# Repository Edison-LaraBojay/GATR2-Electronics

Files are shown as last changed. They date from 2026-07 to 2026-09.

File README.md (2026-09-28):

# GATR2 Electronics

Electronics, firmware, shared protocols, Raspberry Pi sensing software, and V5
Brain navigation libraries for the GATR2 VEX robot.

```text
encoders / IMU -> RP2040 acquisition -> Raspberry Pi estimation <-> V5 Brain
camera / other Pi-connected sensors ----------^
```

The Pi combines timestamped sensor measurements into robot localization and
information about a requested physical landmark. The Brain asks for them over a
request/reply link and owns destinations, alignment behavior, mechanisms, and
motor control.

## PCBs

The [PCB overview](pcb/README.md) links each board family. Its README explains
the general purpose, and the iteration folders document changes, test results,
and KiCad project files.

| Board family | Purpose |
|---|---|
| [Pi HAT](pcb/PiHat/README.md) | Plugs into the Pi's 40-pin header to reduce loose wiring and provide dedicated sensor and Brain connections. |
| [IMU](pcb/IMU/README.md) | Inertial measurements for attitude estimation, primarily heading. |
| [Magnetic encoder](pcb/MagneticEncoder/README.md) | Contactless rotation sensing for compact custom tracking-wheel assemblies. |

## Pi runtime

Start with [Set up and run Navigatr](pi/naviGATR/docs/setup.md) for Pi/Pico setup,
building, camera calibration, mounting measurements, two- and three-wheel IMU +
camera configurations, and the live field viewer.

The [Navigatr overview](pi/naviGATR/README.md) is the entry point for the Pi
runtime design, implementation coverage, and build commands. Its design uses
one program with independently scheduled localization and landmark-estimation
pipelines, standard stage inputs and outputs, and timestamped pose history.
Neither pipeline requires a particular sensor family or relative execution rate.

Robot position and field-object positions use configured field coordinates.
Field estimation starts with nominal landmark poses and can update them from
accepted observations. The Pi sends nothing unasked: each Brain request gets
one reply. A state reply carries the robot pose with its measurement age and
anchor identity; the field map (objects and their obstacle boxes) and the
current field-object estimates, labeled nominal or observed, are read as
chunked documents. Headings on the wire are full field headings, and the Brain
applies its own destination offset. The inspection viewer also displays
heading differences from nominal orientation. See the landmark documentation
for selection and retention behavior, and the
[brain link](docs/interfaces.md) for the wire contract.

- [Architecture and scheduling](pi/naviGATR/docs/architecture.md)
- [Coordinates and heading](pi/naviGATR/docs/coordinates.md)
- [Landmark reporting and retention](pi/naviGATR/docs/landmarks.md)
- [Inspection service and browser viewer](pi/naviGATR/docs/inspection.md)
- [Pi camera setup and libcamera build](pi/naviGATR/docs/pi_camera_setup.md)

A hardware-free demo (`pi/naviGATR/config/demo/`) drives the whole runtime
from a synthetic rig and serves the field viewer on loopback; the README above
has the run and SSH port-forward commands.

## Brain

[`brain/`](brain/README.md) holds portable C++ libraries with host tests and
the PROS programs that compile them in place.

- [investiGATR](docs/investigatr.md): path planning, direct and around the
  field's obstacle boxes, and the shared Brain types.
- [communiGATR](docs/communigatr.md): the Brain side of the Pi link over USB or
  RS-485: robot profile upload, field map, placement, calibration and recovery.
- [actuGATR](docs/actugatr.md): `goToDirect` and `goToAvoiding`, path
  following, tank and mecanum drives.

The Brain describes the robot (tracking wheels, IMU, footprint) and sends it
to the Pi as a robot profile; see [Brain setup](docs/brain_setup.md) for
configuration, calibration and the two test programs. The libraries are host
tested and compile in the PROS build; none of the Brain code has run on the
robot yet.

## Repository map

- [`pcb/`](pcb/) - KiCad boards, symbols, footprints, and hardware revisions.
- [`pico/aggreGATR/`](pico/aggreGATR/README.md) - RP2040 acquisition firmware.
- [`pi/naviGATR/`](pi/naviGATR/README.md) - Pi sensing and estimation runtime, with the spectaGATR browser viewer.
- [`brain/`](brain/README.md) - V5 Brain libraries (investiGATR, communiGATR, actuGATR) and PROS programs (locaGATR, operaGATR).
- [`translaGATR/`](translaGATR/) - shared wire codec used by the Brain, Pi and Pico.
- [`bench/`](bench/) - host and hardware bring-up utilities.
- [`docs/`](docs/) - supporting hardware, interface, and setup material; [component names](docs/naming.md).

## Hardware and bring-up references

- [Contributing](CONTRIBUTING.md)
- [Hardware architecture](docs/hardware.md)
- [Shared interfaces and wire frames](docs/interfaces.md)
- [Raspberry Pi setup](docs/pi_setup.md)

Physical values require measurement or independent verification. A `.xml.in`
configuration contains unresolved values and is not a deployment profile.

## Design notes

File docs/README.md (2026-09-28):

# Documentation

## Runtime and configuration

- [Set up and run Navigatr](../pi/naviGATR/docs/setup.md): complete Pi/Pico bring-up,
  camera calibration, robot geometry, three-wheel camera configurations, and the
  live viewer.
- [Parallel-wheel bring-up](../pi/naviGATR/docs/parallel_wheel_bringup.md): the
  current robot's systems test, two parallel wheels + BNO08X, localization
  first and camera second.
- [Navigatr](../pi/naviGATR/README.md): build, run, demo, and implementation coverage.
- [Configuration](../pi/naviGATR/docs/configuration.md): default profile, command-line
  overrides, inline XML, and referenced fragments.
- [Architecture](../pi/naviGATR/docs/architecture.md): construction, stage contracts,
  localization, field estimation, and workers.
- [Coordinates](../pi/naviGATR/docs/coordinates.md): frames, heading, camera offsets,
  measurement time, and pose history.
- [Landmarks and targets](../pi/naviGATR/docs/landmarks.md): association, retained
  field estimates, target resolution, and the actual Brain output.
- [Resources](navigatr_resources.md) and [sensors](navigatr_sensors.md): registered
  implementations and their configuration contracts.
- [Inspection](../pi/naviGATR/docs/inspection.md): the spectaGATR browser
  viewer, the `navigatr.inspect/2` feed (state, diag, telemetry,
  instrumentation), latency terms, live graphs and replay.
- [Capture and export](../pi/naviGATR/docs/capture.md): bounded Pi-side
  recording with manual and automatic triggers, the ZIP of CSVs and its
  metadata.
- [Camera preview](../pi/naviGATR/docs/camera_preview.md): live camera
  pictures on the Brain-profile USB setup without field correction.
- [Pico link](../pi/naviGATR/docs/pico_link.md): Pico identity, status,
  commands, the optional diagnostic frame and the link instrumentation.
- [Viewer perf harness](../pi/naviGATR/tools/perf/README.md): the inspection
  and browser latency baseline and how to rerun it.

## Brain

- [Brain setup](brain_setup.md): where robot settings live, building and
  uploading, the localization test and drive test programs, wheel and IMU
  calibration, placement, recovery, and what is not yet hardware validated.
- [investiGATR](investigatr.md): path planning and the shared Brain types
  (field, state source, references, motion model, paths); planner method,
  exits by walls, cost and limits.
- [communiGATR](communigatr.md): the Pi link over USB or RS-485: sessions,
  robot profile, field transfer, placement, calibration, recovery, timing,
  PROS packaging.
- [actuGATR](actugatr.md): movement commands, path following, tank and
  mecanum drives, drive ownership, tuning.
- [Brain folder](../brain/README.md): libraries, PROS programs, and the host
  build.

## Hardware and deployment

- [PCB overview](../pcb/README.md): board families, revisions, and validation status.
- [Hardware](hardware.md): sensor roles, firmware settings, and communication wiring.
- [Pico firmware](../pico/README.md): acquisition and sensor telemetry.
- [Wire interfaces](interfaces.md): Pico sensor frames and control, and the brain
  link v4 request/reply protocol (sessions, profile, documents, bus timing).
- [Pi access](pi_setup.md): SSH and provisioning.
- [Pi camera setup](../pi/naviGATR/docs/pi_camera_setup.md): libcamera build and
  capture checks.
- [Field assets](../pi/naviGATR/docs/field_assets.md): nominal Override geometry and
  its CAD sources.
- [Calibration inventory](../pi/naviGATR/docs/calibration_inventory.md): required
  robot measurements and template values.
- [Attitude firmware follow-up](../pi/naviGATR/docs/attitude_firmware_followup.md):
  the work needed to provide live roll and pitch.
- [RS-485 bench test](../bench/rs485_link/README.md): independent transmit bring-up.

[Component names](naming.md) lists every -GATR name, what it does and why
it fits, and the renames with migration steps.

[Contribution conventions](contributing/README.md) describe the repository layout
and how to add board families and revisions. Host tests and synthetic demos verify
software behavior; hardware validation status is recorded in the relevant board
and deployment documents.

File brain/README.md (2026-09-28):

# brain

V5 Brain software. The libraries are portable C++ with host tests; PROS
programs compile them in place from this folder.

- [`investiGATR/`](investiGATR/README.md): path planning (direct and obstacle
  avoiding) and the shared Brain types: field, state source, references,
  motion model, paths.
- [`communiGATR/`](communiGATR/README.md): the Pi link over USB or RS-485:
  sessions, robot profile upload, field map and estimates, placement,
  calibration and recovery, wheel calibration, telemetry and VEX IMU tilt
  for the Pi viewer.
- [`actuGATR/`](actuGATR/README.md): movement: `goToDirect` and
  `goToAvoiding`, path following, tank and mecanum drives, the drive task.
- [`robot/`](robot/README.md): this robot's description (tracking wheels,
  IMU, footprint, link, start pose), shared by the programs.
- [`locaGATR/`](locaGATR/README.md): motor-free bench
  program: placement, pose, IMU and wheel calibration, recovery history.
- [`operaGATR/`](operaGATR/README.md): drive program: direct, avoiding and
  landmark tests, manual driving, tuning.
- `gatr2_brain.mk`: make fragment that compiles the libraries into a PROS
  project.
- `CMakeLists.txt`: host build and tests of the three libraries.

Host build and tests, from the repository root (the CI job `brain` runs the
same commands; CI does not build the PROS programs):

```
cmake -S brain -B build-brain
cmake --build build-brain -j
ctest --test-dir build-brain --output-on-failure
```

Setup, calibration, tuning and the test programs:
[Brain setup](../docs/brain_setup.md). Libraries:
[investiGATR](../docs/investigatr.md), [communiGATR](../docs/communigatr.md),
[actuGATR](../docs/actugatr.md), [wire interface](../docs/interfaces.md).
Nothing here has run on the robot yet.

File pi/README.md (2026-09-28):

# Raspberry Pi sensing runtime

[`naviGATR`](naviGATR/README.md) combines timestamped measurements into a robot
pose and configured field-object estimates. Target resolution can latch a desired
robot pose for a requested target; the V5 Brain owns motor control.

The runtime uses independently scheduled estimation and field
pipelines in one program. Each pipeline has defined inputs and outputs; its
implementation determines which sensors and algorithms it uses.

Start with [Set up and run Navigatr](naviGATR/docs/setup.md) for the complete
hardware, calibration, configuration, build, and viewer workflow. The
[runtime overview](naviGATR/README.md) describes implementation coverage; then read:

- [Architecture and scheduling](naviGATR/docs/architecture.md)
- [Coordinates, heading, and measurement time](naviGATR/docs/coordinates.md)
- [Field estimates, targets, and reporting](naviGATR/docs/landmarks.md)

The overview includes implementation coverage and build commands.

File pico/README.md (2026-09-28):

# pico

RP2040 software for the Pi HAT.

- [`aggreGATR/`](aggreGATR/README.md): the acquisition firmware (PlatformIO project). It gathers the encoder counts and IMU readings into timed frames for the Pi. Build it from `pico/aggreGATR` with `pio run`.

Component names: [docs/naming.md](../docs/naming.md).

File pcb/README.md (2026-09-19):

# PCBs

Custom boards for the GATR2 sensing system. Each board folder explains its
general purpose and contains its numbered iterations. Each iteration has its
own README describing changes, status, and KiCad project files.

## Boards

| Board | Purpose |
|---|---|
| [Pi HAT](PiHat/README.md) | A stable connection through the Pi's 40-pin header, with dedicated sensor and peripheral ports to reduce loose wiring. |
| [IMU](IMU/README.md) | Inertial measurements for robot attitude estimation, primarily heading. |
| [Magnetic encoder](MagneticEncoder/README.md) | Contactless rotation sensing for compact custom tracking-wheel assemblies. |

## Working with a board

Choose a board, then an iteration, and open the `.kicad_pro` linked from its
README. Keep the schematic, layout, and accompanying libraries together.

The Pi HAT symbol tables and the magnetic encoder's symbol table still contain
workstation-specific library paths. The Pi HAT's custom symbols are included in
its `RP4Pinout/` directory; library paths may need updating when editing on
another machine. Project locations and library notes are linked from each
revision README.

When a revision changes, update its short description and the comparison with
the previous revision. Record fabrication or test results alongside that
revision when available. The schematic remains the source for the BOM and
connector pin assignments.

For new boards and iterations, follow the
[PCB contribution guide](../docs/contributing/README.md).

## Related documentation

- [Hardware parts and rationale](../docs/hardware.md)
- [RP2040 acquisition firmware](../pico/README.md)
- [Pi sensing and estimation software](../pi/navigatr/README.md)
- [Shared interfaces](../docs/interfaces.md)

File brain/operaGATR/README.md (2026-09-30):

# brain/operaGATR

PROS drive program for the V5 Brain: localization from the Pi through
communiGATR, planning from investiGATR, following and drive control from
actuGATR. It runs a direct, an avoiding and a landmark-relative test, drives
manually, and shows the command state for tuning. Built with the PROS
toolchain; manual driving has been tested, and autonomous following still
needs hardware verification.

The current test uses USB to the Pi, a VEX IMU on Smart Port 20, a forward
tracking wheel on Pico port 1 and a sideways wheel on port 0. Four-motor
mecanum is selected, with one independently driven motor per corner, confirmed
blue 600 RPM cartridges and 1:1 direct drive (motor, shaft, wheel). Tracking
wheels remain approximately 48 mm in diameter with 4,000 counts per turn.
Temporary distance multipliers in `brain/robot/gatr2_robot.h` are **2.10144**
for the forward wheel (port 1) and **1.96700** for the sideways wheel (port 0),
from separate 23-inch pushes that reported 0.278 m and 0.297 m respectively.
These multiply the radius sent in the robot profile because the existing Pi
limits `travel_scale` to 0.9–1.1; the transmitted radii are effective calibration
values, not physical wheel sizes. Rebuild/upload the Brain and restart its
program to send the profile; no Pi update is needed. Repeat the distance test
before path testing. Reset these multipliers to 1.0 before correcting the
underlying CPR, gearing or wheel diameter. Port 2 retains its nominal radius.
The driven-wheel rectangle is 22.3 cm wide between tread centerlines and
24.2 cm long between front/rear shafts; its center is the robot origin.

The mecanum wheels are approximately 70 mm in diameter. Motor Smart Ports are
front-left 12, front-right 11, rear-left 2 and rear-right 1, named while facing
forward from behind the robot.
The reversal flags in `include/robot_config.h` set ports 2/12 normal and
ports 1/11 reversed so positive wheel commands should roll forward. Verify
forward/backward, strafe and turning with this configuration before path tests.
The tracking-wheel perpendicular offsets in `brain/robot/gatr2_robot.h` use these approximate
measurements: the forward wheel is at the right tread centerline, giving
y = -11.15 cm; the sideways wheel is assumed 11 cm behind the front axle,
giving x = +1.1 cm. Robot +x is forward and +y is left.
Both tracking encoders use `reversed = true`. At field heading 0 degrees,
a forward push should increase X and a leftward push should increase Y;
confirm those signs after uploading before running a path.
The outer body measures approximately 33.7 by 29.3 cm. Its footprint uses
16.85 cm forward/backward and 14.65 cm left/right from the drivetrain origin:
front/back overhangs are roughly equal, and left/right symmetry is assumed.
Refine individual extents if needed before close obstacle passes.
The geometry is approximate; motor/encoder directions and gains still need
checking and tuning on the robot.

Mount the mirrored wheels so the roller directions form an X when viewed from
above. Matching wheel types occupy opposite diagonals. The motor groups are
front-left, front-right, rear-left and rear-right; motor reversal makes each
wheel roll forward for a positive command, and cannot correct a misplaced
wheel type. The software does not have a per-wheel A/B handedness option.

Keep the robot still at startup. Once the profile, sensors and placement are
ready, its initial pose is (7 inches, 24 inches, 0 degrees). Left stick Y drives forward/back,
left stick X strafes, and right stick X turns (robot-relative controls).
Press A with the sticks released to plan from the
current pose to the fixed target (72 inches, 24 inches, 90 degrees), without
obstacle checks. X uses that same target with obstacle avoidance.
Moving manually first changes the path's start, not its target.
On the configured field, the direct route crosses `red_goal_3_south` near
(46.66 inches, 23.11 inches), so use X with the field assembled. The initial
rear clearance to the red wall is only about 9 mm with the approximate
footprint. Avoidance supports a straight exit from this near-wall placement.
The holonomic follower can translate and change heading at the same time.
B cancels; moving the sticks also takes over. UP reassigns the current pose to
the initial pose, so only use it after returning to the physical starting spot.
Encoder directions and follower gains still need checking on the robot.
To request a fresh VEX IMU calibration, press DOWN while stopped, keep the
robot still until it finishes, then press UP at the physical starting spot.

The Pi still serves the pose and path visualization; no camera is required.
Use `pi/naviGATR/config/override/brain_profile_usb.xml`. The Brain sends these
robot measurements to the Pi, so changing them only requires rebuilding and
uploading this Brain program. A ignores obstacles and field bounds; X/Y
check them using the configured footprint and planning clearance.

Edit the initial pose in `brain/robot/gatr2_robot.h`: `kStartX`, `kStartY`
(inches multiplied by `kInch`) and `kStartHeadingDegrees` (degrees).
Edit `kDirectGoal` in `include/robot_config.h` for the A/X destination:
`{x_inches * kInch, y_inches * kInch, heading_degrees * kDeg}`.
`kAvoidGoal` takes the same value automatically. Keep the robot's physical
center at the configured start and facing the configured heading at startup,
or when using UP to reassign its pose.

- `include/robot_config.h`: drivetrain (tank or mecanum example), motor
  ports and directions, limits, follower gains, manual speeds, test
  destinations, startup placement. PLACEHOLDER values are not measured.
- `include/field_references.h`: generated field object names
  (`Field::RedGoal2West`, ...) for the map id the Pi serves.
- `src/main.cpp`: link and drive setup, the screen, `autonomous()`,
  `opcontrol()`, `disabled()`. The actuGATR drive task is the only motor
  writer.
- The robot description (tracking wheels, IMU, footprint, link, start pose)
  is shared with locaGATR in
  [brain/robot/gatr2_robot.h](../robot/gatr2_robot.h).
- `Makefile`: PROS kernel 4.2.2 project that compiles the libraries in place
  through [brain/gatr2_brain.mk](../gatr2_brain.mk).

Kernel files (`firmware/`, `include/pros/`) are not in git. Restore them once,
offline, in this folder:

```
pros c apply kernel@4.2.2 --force-apply --no-download
git checkout -- .gitignore
pros make
pros upload --slot 1 --name operaGATR --after screen
```

The CLI replaces `.gitignore` with its template copy, hence the checkout.

Controls, tests, tuning and the planner limits:
[Brain setup, section 7](../../docs/brain_setup.md#7-drive-test-program).

While the link is disconnected, the screen replaces the button hints with
connection diagnostics from the existing status snapshot. `I/O on` means
the Brain transport is initialized, not that the Pi has answered. USB `tx`
counts complete line writes, `rx` decoded incoming frames, and `short`
incomplete writes. `Reply` counts correlated protocol replies, `TO` timeouts,
`bad` invalid reply frames, and `stray` valid replies without a matching
request. The last diagnostic row shows USB read errors/dropped lines and
whether the polling task started, or an explicit protocol mismatch.
Photograph these rows if the program remains at connecting; the counters
distinguish a transmit stall, missing responses, and rejected responses.

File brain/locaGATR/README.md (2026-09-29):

# Localization test

Motor-free PROS bench program for checking naviGATR localization. It sends
the robot profile from [brain/robot/gatr2_robot.h](../robot/gatr2_robot.h)
to the Pi, places the robot once at program start, and shows pose,
readiness, sensors and recovery history on the Brain screen. It also runs
the per-wheel travel calibration and IMU recalibration. Move the robot by
hand. Built with the PROS toolchain; not yet run on a robot.

Current bench setup (all in `gatr2_robot.h`):
- USB link to the Pi;
- two perpendicular tracking wheels, forward on encoder port 1 and sideways
  on port 0;
- the VEX IMU on Smart Port 20.

The Pi runs `config/override/brain_profile_usb.xml`. No BNO08X, camera or
AprilTags are needed.

- `include/robot_config.h`: startup placement policy and wait, wheel
  calibration reference distance and limits, pose age limit, loop periods.
- `src/main.cpp`: three pages (Status, Wheel calibration, Recovery). Every
  link call is in its first section.
- `Makefile`: PROS kernel 4.2.2 project that compiles the libraries in place
  through [brain/gatr2_brain.mk](../gatr2_brain.mk).

Kernel files (`firmware/`, `include/pros/`) are not in git. Restore them once,
offline, in this folder:

```
pros c apply kernel@4.2.2 --force-apply --no-download
git checkout -- .gitignore
pros make
pros upload --slot 2 --name locaGATR --after screen
```

The CLI replaces `.gitignore` with its template copy, hence the checkout.

Pages, controls, the calibration procedure and recovery:
[Brain setup, sections 3 to 6 and 8](../../docs/brain_setup.md#3-locaGATR-program).
Pi build and service: [Brain setup, section 2](../../docs/brain_setup.md#2-build-and-upload).

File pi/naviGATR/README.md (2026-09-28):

# navigatr

`navigatr` is the Raspberry Pi sensing runtime for the GATR2 VEX robot. It
combines measurements into a robot pose and field-object estimates. Configured
target resolution can turn a requested target into a desired robot pose; the
Brain owns movement control and motor commands.

Robot position and reported landmark position use the configured field
coordinates. Robot heading is its orientation in that field. The landmark's
inspection `heading_error` is its estimated rotation away from nominal, wrapped
to `(-180, 180]` degrees. The brain link answers Brain requests only. Its field
documents carry every configured object: the map with collision boxes, and the
estimates as physical poses with full field heading, labeled nominal or
observed. Configured targets stay on the Pi.

**Robot configuration comes from the Brain.** The primary configs,
[`config/override/brain_profile_usb.xml`](config/override/brain_profile_usb.xml)
and [`brain_profile_rs485.xml`](config/override/brain_profile_rs485.xml), hold
only the Pi's devices, wired ports and tuning; the Brain sends the tracking
wheels, encoders, IMU source and footprint as a typed robot profile, and the
Pi builds its localization from it. See [Brain robot profiles](docs/brain_profile.md).

## Runtime design

**First setup:** [Set up and run Navigatr](docs/setup.md) starts with the
Brain-profiled robot, then covers Pi/Pico provisioning, build commands, camera
calibration software, robot and camera geometry, the XML-configured
three-wheel IMU + camera templates, launch commands, and output locations. The
two parallel wheels + BNO08X XML profiles have their own
[bring-up guide](docs/parallel_wheel_bringup.md). The current bench (USB, VEX
IMU, forward and sideways wheels) is in [USB bench](docs/usb_localization_bench.md);
[Pi setup and automatic startup](../../docs/pi_setup.md) covers Ethernet
access, building, and starting naviGATR on every boot.

These documents describe the implemented runtime and data contracts. Hardware
integration still needs the checks recorded in the deployment documents.

| Document | Responsibility |
|---|---|
| [Brain robot profiles](docs/brain_profile.md) | The Brain-profiled configs: who owns what, apply and continuity, supported setups and refusals, corrections applied once, calibration and stationary handling, CONTROL, sensor loss and recovery. |
| [USB bench](docs/usb_localization_bench.md), [VEX IMU bench](docs/vex_imu_bench.md) | The current bench: USB link, forward and sideways wheels, the Brain VEX IMU. |
| [Pico link](docs/pico_link.md) | Pico identity, status, commands and the serial reopen. |
| [Configuration](docs/configuration.md) | Run commands, the compiled default file, inline XML, and nested file references. |
| [Architecture](docs/architecture.md) | Captured resource/sensor functions, ResourceMap and SensorMap result contracts, all runtime paths, nested stage I/O, workers, and pose history. |
| [Coordinates](docs/coordinates.md) | Field and robot axes, heading, camera mounting, attitude, and measurement-time transforms. |
| [Landmarks](docs/landmarks.md) | Nominal and observed field state, association, target resolution, and Brain output. |
| [Inspection](docs/inspection.md) | The `navigatr.inspect/2` feed, flow control and latency terms, the service, and the spectaGATR browser viewer. |
| [Capture](docs/capture.md) | Bounded Pi-side diagnostic recording, triggers, the ZIP/CSV bundle and its metadata. |
| [Camera preview](docs/camera_preview.md) | The camera shown on the Brain-profile USB setup with no field correction. |
| [Perf harness](tools/perf/README.md) | Inspection and viewer latency measurements: baseline, rerun, compare. |
| [Localization fusion](docs/localization_fusion.md) | Noise units, the weighted step, covariance propagation, and what the fusion estimator does not model. |
| [Field assets](docs/field_assets.md) | Official Override CAD source, revision, units, axis conversion, planning data (boundary, wire ids, collision boxes), and what the field file was checked against. |
| [Calibration inventory](docs/calibration_inventory.md) | Every remaining measurement, where it goes, and what it gates. |
| [Pi camera setup](docs/pi_camera_setup.md) | libcamera stack, build flag, capture mode, exposure timing convention, hardware checks still to run. |
| [Attitude follow-up](docs/attitude_firmware_followup.md) | What the Pico firmware would have to send for live tilt. |

## What runs

One executable, built once from a configuration, with two workers and an
optional inspection service:

```text
construction   parse -> make_resources -> make_sensors -> make_localization
               -> make_world_estimation -> target resolution, publishing slots
               -> freeze (any failure destroys the candidate)

estimation     resources -> sensors -> commands -> localization
worker         -> target resolution + publishing against the newest field snapshot
(loop rate)    -> hands the sensor snapshot to the field worker (latest wins)

field worker   world estimation (apriltag: extraction -> association -> landmarks)
(event driven) -> publishes an immutable FieldSnapshot and the detection frame
               bound to its exact image identity

inspection     reads snapshots only; JSON + JPEG over loopback HTTP/WebSocket
service        at its own rate; a slow browser is skipped, never waited for
```

Localization is a self-contained component: configured robot-observation
functions grouped by measurement model (`tracking_wheel_motion`,
`imu_heading_increment`, `attitude_reference`, and the Brain VEX IMU bench
models `brain_imu_planar_bench` and `brain_imu_parallel_bench`), one state estimator
(`planar_motion_integrator`, or `weighted_planar_fusion` with an explicit
uncertainty model and a pose covariance), and a history ring of recent poses that only
localization writes. Readers get copied snapshots or synchronized timestamped
lookups (`RobotStateFeed`). Every mutable state has one writer; `reset()` stops
both workers, resets every stage once, and restarts them.

## Implementation coverage

Implemented and covered by host tests:

- Aggregate stages `make_resources`, `make_sensors`, `make_localization`,
  `make_world_estimation` with captured executors; typed result maps with receipt, provenance, sequence and
  epoch preserved through derived records.
- Tracking-wheel odometry with gyro heading, per-source interval alignment,
  encoder rebase on a source restart, rejection of nonpositive intervals, no
  endpoint bridging of invalid spans; optional attitude (quaternion) reconciled
  with the planar heading, aged separately, level fallback labeled assumed.
- Covariance-weighted fusion (`weighted_planar_fusion`): three wheels plus an
  independent gyro blended by configured noise, translation re-solved through
  the wheel geometry, pose covariance propagated; the checked-in
  `config/demo/synthetic_fusion_demo.xml` runs it against the rig.
- Pose history ring (binary search, shortest-arc yaw interpolation, attitude
  slerp, gap and epoch gates, explicit lookup statuses).
- Real AprilTag detection (vendored AprilRobotics detector, `tagCircle21h7` and
  the other supported families) with 2D decoding without calibration, metric
  poses only with intrinsics and a configured corner size, distortion undone
  before the solve, every decoded tag visible with its association decision.
- Capture-time transform chain with the camera offset, mounting rotation and
  measured tilt; association by full pose against every mount sharing an id.
- Two-worker scheduling with a bounded latest-frame handoff, per-worker rate
  and drop counters, orderly shutdown.
- Inspection feed `navigatr.inspect/2` (latest-state delivery with ping/pong
  flow control, separate state and diag messages; the full `inspect/1`
  snapshot stays at `GET /api/snapshot`), the service, and the spectaGATR
  three.js viewer (field, robot and attitude, trail, nominal vs estimated
  landmarks, camera image with identity-bound overlays, status badges,
  diagnostics, latency panel, live graphs, transport instrumentation,
  capture controls and ZIP replay).
- Diagnostics: a bounded `DiagnosticsHub` fed by the runtime's producers,
  always-on link counters, and a Pi-side capture service with triggers that
  writes a store-only ZIP of CSVs.
- A synthetic rig resource that drives the real pipeline without hardware:
  encoder counts, gyro with bias, attitude (measured or unavailable), rendered
  camera frames of the configured field, a displaced landmark.

Implemented but not run on hardware (see the Pi camera setup document for the
exact checks): the libcamera capture backend (`libcamera_camera`, built only
with `-DNAVIGATR_WITH_LIBCAMERA=ON` on the Pi) including exposure timestamp
mapping and buffer ownership.

Implemented and host tested, not run on hardware:

- The brain link (`brain_link` command collection and publishing, Brain link
  v4 sessions, per-session dedupe, placement acknowledged only once applied)
  over the half-duplex `linux_serial_link` (`DriverEnable`) or the Brain USB
  port (`pros_usb_link`). The hardware checks are in
  [Connect the Brain](docs/setup.md#hardware-checks-still-to-do).
- Brain robot profiles: staging, validation, capability checks, the candidate
  built from Pi templates, the controlled boundary and its continuity rules,
  every supported topology and IMU source, each correction applied once.
- Field documents for Brain planning (map with collision boxes, estimates of
  every object), chunked and retained.
- One stationary window for every IMU bias path, bounded calibration with
  gated bias upkeep, zero velocity while stationary; CONTROL recalibrate,
  reinitialize, Pico IMU reinit and acquisition restart; READ_WHEELS.
- Recovery: a used source that drops ends pose continuity (the Brain places
  again); Pico identity and restarts; serial reopen; a bounded event log.
- Inspection of all of it: the Brain link state, profile, wheels, calibration,
  Pico link, events and path, and the field's planning data in the viewer.

Deferred, deliberately:

- Live tilt from the Pico: the firmware sends gyro Z alongside encoders; the
  protocol has optional accel XY fields, but the firmware does not populate
  them, so Pico IMU profiles show attitude `assumed_level`. Brain VEX IMU
  profiles get roll and pitch from Brain TELEMETRY for display and recording
  (`measured`, then `stale` 250 ms after the last report); VEX sign
  conventions are not yet checked on hardware. The estimator attitude path is
  exercised by the synthetic rig.
- Manual exposure and gain control for the camera (auto exposure is used).
- Measured calibration values for the GATR2 robot: the robot templates stay
  `.xml.in` until measured (see the calibration inventory).

Synthetic tests and desktop browser checks do not establish Pi camera
performance or physical alignment accuracy.

## Configuration and calibration

XML selects registered implementations and supplies their configuration. IDs are
opaque references. Startup checks reject missing producers, incompatible payloads,
duplicate outputs, and invalid calibration.

- [`config/shared/robots/`](config/shared/robots/): the GATR2 robot templates
  (`.xml.in`, measured values required), the uncalibrated camera fragment for
  live inspection, and the synthetic rig fragments.
- [`config/shared/pipelines/`](config/shared/pipelines/): the parallel-wheel
  pipelines and their shared localization, three-wheel diagnostic pipelines, the
  synthetic demo pipeline, and the camera-only inspection pipeline.
- [`config/override/brain_profile_usb.xml`](config/override/brain_profile_usb.xml),
  [`brain_profile_rs485.xml`](config/override/brain_profile_rs485.xml): the
  primary robot configs; the Brain supplies the robot profile.
- [`config/override/field.xml`](config/override/field.xml): nominal Override
  geometry for nine goals and their tag mounts, the planning data (boundary,
  wire ids, collision boxes), plus display dimensions and static features.
- [`config/override/diagnostics/`](config/override/diagnostics/): the
  XML-configured profiles: the VEX IMU bench profiles, the parallel-wheel
  profiles (runnable once their robot file is measured), composed three-wheel
  profile templates, and the runnable live camera inspection profile.
- [`config/demo/`](config/demo/): hardware-free demo profiles.
- [`config/examples/modular/main.xml`](config/examples/modular/main.xml): a minimal
  runnable scaffold with separate Resources, Sensors, Pipeline, and Localization files.

Files ending in `.xml.in` contain unmeasured or unresolved values and cannot be
loaded. `calibration_status` is an optional reader annotation that runtime
does not interpret; actual parameter values and geometry are validated.
Display metadata (`Dimensions`, `Feature`,
`Visual`) never feeds an estimate.

## Build

Host (Windows, Git Bash, from `pi/naviGATR`):

```text
export PATH=/c/msys64/ucrt64/bin:$PATH
cmake -S . -B build -G "MinGW Makefiles" -DCMAKE_BUILD_TYPE=Debug
cmake --build build -j8
ctest --test-dir build --output-on-failure
```

Pi (Raspberry Pi OS, from `pi/naviGATR`; packages in the Pi camera setup
document):

```text
cmake -S . -B build -DCMAKE_BUILD_TYPE=Release -DNAVIGATR_WITH_LIBCAMERA=ON
cmake --build build -j4
ctest --test-dir build --output-on-failure
```

Without `NAVIGATR_WITH_LIBCAMERA`, selecting `libcamera_camera` is a
configuration error naming the missing backend; nothing pretends to capture.

## Run

```text
./build/navigatr [--config_file="profile.xml"] [--inspect-port <n>]
                 [--cycles <n>] [--inline] [--replay <resource_id>=<capture.bin>]
```

- With no filename, the initial compiled default is
  `config/demo/synthetic_field_demo.xml`. Select another at build time with
  `cmake -S . -B build "-DNAVIGATR_DEFAULT_CONFIG=config/my_robot.xml"`, then rebuild.
  The chosen path is baked in; XML contents are read on each startup.
- `--config_file` overrides that choice for one run; `--config-file` and the
  positional filename also work. `--help` prints the compiled default path.
- Default execution: workers plus the inspection service when the profile enables it.
  Ctrl-C stops the service, then the workers, then the system.
- `--inline` runs every stage on one thread at the loop rate (replay, bench).
  The brain link needs the default workers; `--inline` with it prints a warning.
- `--inspect-port` enables the inspection service on loopback without editing
  the profile.

Hardware-free demo with the viewer:

```text
./build/navigatr
./build/navigatr --config_file="config/demo/synthetic_field_demo_no_attitude.xml"
./build/navigatr --config_file="config/demo/synthetic_fusion_demo.xml"
```

The robot, configured from the Brain (Pi; RS-485: `brain_profile_rs485.xml`):

```text
./build/navigatr --config_file="config/override/brain_profile_usb.xml"
```

It waits for the Brain's profile; `event: ...` lines log applies, refusals,
sensor loss and recovery.

Live camera inspection before metric calibration (Pi, libcamera build):

```text
./build/navigatr --config_file="config/override/diagnostics/live_camera_inspection.xml"
```

From the viewing computer, forward the port and open the page:

```text
ssh -N -L 8765:127.0.0.1:8765 <user>@<pi-host>
http://127.0.0.1:8765/
```

The browser smoke test (`tools/viewer_smoke.sh`) starts the demo, loads the
page headless, and checks that states and a detection frame arrived. The
full browser suite is `py -3 tools/viewer/viewer_tests.py all --binary
build/navigatr.exe` (headless Chrome or Edge; unit, live, no-WebGL,
reconnect, replay, record, slow client, capture failure).

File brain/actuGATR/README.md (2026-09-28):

# actuGATR

Brain-side movement: `Motion` (`goToDirect`, `goToAvoiding`), path followers,
tank and mecanum drive kinematics, the drive owner, PROS motor adapters, and
the TELEMETRY movement and wheel groups (`telemetryOf`).
Plans come from investiGATR; robot state and the field come from any
`investigatr::StateSource` (communiGATR over the Pi link).

- `include/actugatr/`: public headers
- `src/`: portable sources, host and PROS
- `pros/`: PROS-only sources (motor output, drive task)
- `sim/`: host drivetrain sim, simulated state source, test planner
- `tests/`: host tests; `trajectory_gtest.cpp` runs with the real planner

Usage, tuning and limits: [docs/actugatr.md](../../docs/actugatr.md).

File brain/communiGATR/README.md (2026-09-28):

# communiGATR

Brain side of the Pi link (brain link v4) over USB or RS-485. It sends the
robot profile, reads the field map and estimates, places the robot, runs
calibration and recovery actions, and gives planning and control the robot
state as an investiGATR `StateSource`. It does not plan or drive.

- `Client`: the protocol over a `BytePort`, polled with a time; no I/O of its
  own, no threads.
- `LinkDriver`: `StateSource` and `PathSink` over the client, in SI units.
- `RobotProfile`: the robot description, checked with the Pi's rules before
  upload.
- `readiness`: the status summary both programs show.
- `ProsLink` (PROS): one class for both transports, with its own poll task
  and bounded locks. `ProsVexImu` (PROS): the Brain VEX IMU bench source.
- `attitude`: VEX IMU roll and pitch in the robot frame, for TELEMETRY.
- `VexImuRecalibration`: starts the VEX IMU calibration only after the Pi
  reports the robot still.
- `wheel_calibration`, `startup_placement`, `link_events`: application
  helpers.

Folders:

- `include/communigatr/`: public headers (`pros_*.h` are PROS only)
- `src/`: portable sources, host and PROS
- `pros/`: PROS only sources, never built on the host
- `sim/`: host only fake Pi, RS-485 bus, USB console and test rig
- `tests/`: host tests

Docs:

- [communiGATR](../../docs/communigatr.md): API, profile, field sync,
  readiness, recovery, timing, PROS packaging, tests.
- [Wire interface](../../docs/interfaces.md): brain link v4 and documents.
- [Brain setup](../../docs/brain_setup.md): where settings live, build and
  upload, calibration, placement.
- [actuGATR](../../docs/actugatr.md): movement on top of this link.

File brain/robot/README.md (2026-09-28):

# robot

`gatr2_robot.h`: this robot's localization description, shared by the Brain
programs (tracking wheels, encoders, IMU source, footprint, Pi link, start
pose), plus the telemetry switch and the VEX IMU mounting for the viewer's
tilt. The Brain sends the localization part to the Pi as the robot profile on
connect.
Program-specific settings (drive motors, gains, tests, controls) stay in each
program's `include/robot_config.h`.

Calibration and tuning: [docs/brain_setup.md](../../docs/brain_setup.md).

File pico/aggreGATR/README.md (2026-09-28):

# Pico acquisition firmware

RP2040 firmware for the Pi HAT. It reads three A/B quadrature encoder channels
and IMU yaw rate over SPI1, and sends timestamped sensor frames to
the Pi over UART at 50 Hz. Localization runs on the Pi.

The IMU model is picked at build time: a BNO08X (three-axis gyro projected onto
the up axis learned at startup, averaged per frame) or an ASM330LHHG1 (physical gyro
Z). A missing or failed IMU, or a BNO08X still aligning, leaves the gyro bit
clear in the frame; encoders and the UART stream keep running.

[Pins](src/board.h), [rates and build selection](src/config.h), and
[the shared wire format](../../translaGATR/frames.h) define the hardware and protocol.
[docs/interfaces.md](../../docs/interfaces.md) describes the sensor frames and the
Pico control frames. The BNO08X uses CEVA's sh2 driver,
[vendored](third_party/README.md).

## Pi link

- Sensor frames are v2 (type 0x04): each carries `boot_id` (random and nonzero
  per boot, from RP2040 ROSC random bits mixed with the timer), `acq_epoch` and
  `imu_epoch`. The largest frame is 31 bytes and goes out only when the 32-byte
  UART TX FIFO is empty; a tick with a busy FIFO is skipped, never delayed.
- The Pico reads Pi commands (type 0x12) from the same UART without blocking
  and answers in status frames (type 0x13): every 200 ms, and about one tick
  after a command or an IMU state change. A status frame goes only while the
  TX FIFO is empty and at least its airtime plus 1 ms before the next sensor
  tick, so it never delays a sensor frame.
- Commands run only when `target_boot_id` is this boot. The last 4 commands
  (request id, op, body) are recorded; a resend is answered from its record
  and never run again.
  - CONFIGURE sets whether the IMU is enabled (enabled at boot). Disabling
    holds the IMU idle and stops its retries.
  - REINIT_IMU restarts IMU port 0 with fresh quick attempts and a new
    `imu_epoch`; `Running` until the IMU is ready, then `Completed`, or
    `Failed` (ImuAbsent, ImuDisabled, NoSuchPort).
  - RESTART_ACQUISITION zeroes the three encoder counters with interrupts off,
    advances `acq_epoch` and completes at once.
  - DIAGNOSTICS sets the optional diagnostic frame rate (0 off, 1..5 Hz;
    larger values fail BadBody) and completes at once. The rate is 0 after
    every boot.
  - Unknown ops, wrong body lengths and bad values fail with a detail.
- Diagnostic frames (type 0x14, 32 bytes) go only while DIAGNOSTICS set a
  rate, in the same idle windows as status frames and after any due status
  frame: TX FIFO empty and the frame's airtime plus 1 ms before the next
  sensor tick. A busy link delays or thins them; they never delay a sensor
  frame. Each carries:
  - pin levels read back with `gpio_get` (IMU INT, RST, WAKE, CS; encoder A/B
    on all three ports; the UART RX from the Pi). Reading never changes a
    pin's function, direction or pull. These are logic levels sampled once
    per frame, not voltages, and miss fast transitions; the UART RX idles
    HIGH whether or not anything is connected.
  - the IMU driver counters the USB monitor already prints (BNO08X: SHTP
    packets, bad headers, hub resets, last sh2 error, accepted and rejected
    reports, time since the newest accepted report; ASM330: samples read,
    failed probes, configurations and checks, software resets, last failure
    reason);
  - `link_rx_bad`: Pi command frames the command FrameReader rejected (length
    or CRC), and `ticks_skipped`: sensor ticks skipped for a busy TX FIFO.
- Pi software that predates v2 frames ignores type 0x04. Update the Pi before
  flashing this firmware. The Pi side is described in
  [pi/naviGATR/docs/pico_link.md](../../pi/naviGATR/docs/pico_link.md).
- Diagnostics are optional in both directions: a Pi that never asks never
  receives a 0x14 frame, and older firmware answers DIAGNOSTICS with
  UnknownOp, which the Pi shows as diagnostics unavailable. Reflash only when
  you want the diagnostic frames in the viewer.

## IMU retry

While enabled, a failing IMU is retried by the Pico itself; encoders and
frames keep flowing.

- An episode starts at boot, at enable, at REINIT_IMU, or when a device that
  had run for 1 s fails. Five quick attempts wait 0.5, 1, 2 and 4 s between
  them (doubling, capped at 8 s). After the fifth failure the state is
  `Failed` and an attempt runs every 30 s until one succeeds.
- Every (re)initialization advances `imu_epoch`: each BNO08X reset or hub
  reboot and each ASM330 probe.
- The status frame reports state (Disabled, Initializing, Aligning, Ready,
  Retrying, Failed), the last failure reason and the attempts in the episode.
- BNO08X: the supervisor keeps its boot (500 ms), acknowledge (200 ms) and
  stale-stream (100 ms) timeouts. A failed `sh2_open` is retried like any
  other attempt.
- ASM330: a wrong WHO_AM_I is retried, the software reset is polled without
  blocking (100 ms bound), and every 250 ms WHO_AM_I and the gyro
  configuration are checked; two failed checks in a row (an unplugged or reset
  chip) start a new attempt.

Bounded blocking left in the loop: the BNO08X `sh2_open` (10 ms reset pulse,
then up to 200 ms waiting for the boot) until it first succeeds, normally
once in `setup()`, and the BNO08X WAKE handshake (at most 2 ms). A failed
open returns after the pulse.

## BNO08X startup alignment

The driver enables accelerometer report `0x01` at 100 Hz and uncalibrated gyro
report `0x07` at 200 Hz. Keep the robot stationary and level at startup and
after an IMU reset. The fixed IMU mounting can be upside down or sideways.
The accelerometer average defines sensor-space up; projecting all three gyro
axes onto it makes counterclockwise yaw positive.

Alignment needs at least two seconds and 200 unique acceleration samples,
with acceleration magnitude within 0.5 m/s^2 of 9.80665, vector variation at
most 0.25 m/s^2, gyro magnitude at most 0.10 rad/s, and stream gaps/skew at most
50 ms. Motion restarts collection. Yaw remains unavailable until aligned and
both reports are acknowledged and fresh; the status frame shows `Aligning`
meanwhile. The Pi then collects its gyro bias while the robot stays still:
allow about six seconds of stillness for a complete startup.

The learned axis stays fixed until reset. This does not measure live pitch/roll
or compensate dynamic rocking; the Brain still supplies field heading. The
ASM330 path keeps its existing physical gyro-Z behavior. A hub reset repeats
Pico alignment and advances `imu_epoch`, which tells the Pi to restart its bias
calibration. After remounting the IMU, reinitialize it and localization and
repeat the stationary startup.

## Build

One PlatformIO environment per HAT revision and IMU model:

- `hat2_bno08x`, the default: HAT revision 2 with a BNO08X
- `hat2_asm330`: HAT revision 2 with an ASM330LHHG1

```sh
pio run -e hat2_bno08x -e hat2_asm330
```

Upload by hand with `pio run -e hat2_bno08x --target upload` once the board is
connected.

Host tests for the portable logic (IMU retry and supervisors, command handling
and records, status and diagnostic scheduling, diagnostic frame packing,
report decoding and alignment) live in [tests](tests/CMakeLists.txt):

```sh
cmake -S tests -B build/tests && cmake --build build/tests && ctest --test-dir build/tests
```

## USB sensor monitor

The Pico runs by itself; no Pi, Brain, or robot XML is needed for this test.
Flash `hat2_bno08x`, connect the Pico's USB to your computer with a data cable,
and open its serial port at 115200 baud. From `pico/aggreGATR`:

```sh
pio device list
pio device monitor --port COM7 --baud 115200
```

Replace `COM7` with the Pico's listed port (`/dev/ttyACM0` is common on Linux).
Exit the PlatformIO monitor with Ctrl+C. Output updates five times per second:

```text
t_ms=3040 enc0=120 enc1=-48 enc2=0 imu_yaw_mdps=235
```

- `enc0` is J2, `enc1` is J3, and `enc2` is J4. Counts are cumulative since
  Pico startup or the last RESTART_ACQUISITION. Turn each connected wheel by
  hand and check that its count changes and reverses direction. An unused
  channel may stay zero; a reported zero does not prove that an encoder is
  connected.
- `imu_yaw_mdps` is yaw rate in millidegrees per second: `1000` means 1 degree
  per second. Counterclockwise rotation viewed from above should be positive.
  This is rate, not heading, and Pi gyro-bias removal has not been applied.
- `NO_SAMPLE` means that telemetry tick had no usable IMU measurement. This
  is expected during the BNO08X's initial two-second stationary, level alignment;
  it can also mean missing data, a reset, a disabled IMU, or an IMU
  wiring/communication fault. A persistent `NO_SAMPLE` needs investigation;
  it is not a zero rotation rate.

An additional `imu=BNO08X` status line prints once per second:

- `state=WAIT_BOOT` / `RESET_WAIT`: waiting for a hub boot response or holding
  reset before a retry. `DISABLED`: turned off by CONFIGURE. `OPEN_ERROR`:
  sh2 is not open yet; the open is retried. `last` records the last recovery
  cause; `retry` counts recovery attempts since startup, `attempts` the
  attempts in the current episode, and `epoch` the `imu_epoch`. `boot` counts
  actual hub boot notifications.
- `state=WAIT_FEATURES`: waiting for report acknowledgements. `ack=1` means
  acceleration acknowledged, `2` gyro, and `3` both.
- `state=ALIGNING`: report streams are fresh; `cal` shows the current stationary
  acceleration sample count. `READY` means alignment and fresh streams are available.
- `a` / `g` count accepted acceleration/gyro reports since Pico startup; `reject`
  counts rejected callbacks. `age_us` is the last callback's receipt time minus
  its sample timestamp, not the age of the current displayed yaw.
- `rx` counts valid SPI headers, `bad` invalid nonempty headers, and `hdr` is the
  last four SPI header bytes. `int`, `rst`, and `wake` are the Pico pin levels.
  These distinguish a transport problem from calibration; a successful software
  open alone does not prove that the physical IMU responded.

The ASM330 build prints `imu=ASM330 state=... attempts=... reason=... epoch=...
hold_ms=...` instead.

A `link` line follows with the Pi link identity and command state: `boot`
(hex `boot_id`), `acq`, `imu_epoch`, `imu_state`, `reason` and `attempts` as
sent in status frames, `status_sent`, commands received (`cmd`), duplicates
(`dup`), ignored frames, `last` as request id/op/status/detail, the
diagnostic rate and frames sent (`diag_hz`, `diag_sent`), rejected Pi command
frames (`rx_bad`) and `ticks_skipped`.

Counters persist across IMU retries; `last` can therefore describe an earlier
failure even after recovery. Paste several status lines when diagnosing a fault.

The monitor uses the same sample as the 50 Hz binary Pi UART output. It does
not consume another IMU reading or wait for USB to connect; log lines are
skipped when the USB buffer is full. Set `cfg::kUsbDebug` to `false` in
[`src/config.h`](src/config.h) to disable the text output and rebuild.

The Pi link commands, IMU retries, status and diagnostic frames and the pin
read-back have been checked only by the builds and host tests, not on a real
Pico.

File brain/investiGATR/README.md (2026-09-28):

# investiGATR

Brain path planning and the types the Brain libraries share: poses, the field,
the state source interface, movement references, the motion model and paths.
Plans direct or obstacle avoiding paths for tank and holonomic motion models,
with explicit refusals, and revalidates a path after field corrections. No
PROS, motors, following or threads; actuGATR follows the paths.

- `include/investigatr/`: public headers
- `src/`: library sources, host and PROS
- `tests/`: host tests

Types, planner method, exits by walls, cost, limits and tests:
[docs/investigatr.md](../../docs/investigatr.md).

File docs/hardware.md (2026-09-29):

# Hardware parts and rationale

The [PCB overview](../pcb/README.md) describes each board family, iteration, and
reported test status. Open the relevant revision's schematic for connector pins,
component values, and assembly choices; those can differ between revisions.
This page connects the hardware to the checked-in acquisition and Pi runtime.

## IMU

The robot's IMU is a GY-BNO08X breakout on SPI1 (mode 3, at most 3 MHz). The
Pico's [BNO08X driver](../pico/aggreGATR/src/imu_bno08x.cpp) runs CEVA's sh2 library over a
non-blocking SPI layer. It enables acceleration report `0x01` at 100 Hz and
uncalibrated gyro report `0x07` at 200 Hz. At startup or IMU reset, at least two
seconds of stationary, level robot data establish sensor-space up. The driver
projects gyro XYZ onto that fixed axis, allowing sideways and upside-down IMU
mounts. Each 50 Hz frame carries the mean projected yaw rate in millidegrees
per second, with bias left for the Pi. The gyro bit stays clear during alignment
or stale reports. Recovery retries do not stop encoders or UART frames.

Pi HAT v2 wiring, by the module's printed labels:

| Module | Pico | Route |
|---|---|---|
| VCC / GND | 3.3 V / GND | J7 pin 7 / J7 pin 1 or 8 |
| SCL (SCK) | GP10, pin 14 | J7 pin 5 |
| SDA (MISO) | GP8, pin 11 | J7 pin 3 |
| ADO (MOSI) | GP11, pin 15 | J7 pin 4 |
| CS | GP9, pin 12 | J7 pin 6 |
| INT | GP22, pin 29 | J7 pin 2 |
| RST | GP12, pin 16 | added wire |
| PS0/WAKE | GP13, pin 17 | added wire |
| PS1 | 3.3 V | added wire |

PS0 and PS1 must be high through reset to select SPI; the driver resets the hub
with PS0 held high, then uses PS0 as WAKE. The interrupt line is required: the
v3 HAT's six-pin IMU connector drops it. Pins live in
[board.h](../pico/aggreGATR/src/board.h).

The earlier [IMU board](../pcb/IMU/README.md) with the ASM330LHHG1 stays
selectable with the `hat2_asm330` build ([driver](../pico/aggreGATR/src/imu_asm330.cpp)):
208 Hz, 2000 degrees/second full scale, 70 millidegrees/second per LSB, newest
sample per frame, accelerometer disabled.

Keep the robot level and still at a full startup: about two seconds for BNO08X
alignment, then the Pi's gyro bias window (2 s by default with a Brain profile,
200 samples, about 4 s, in the XML parallel-wheel profiles). The
[bring-up guide](../pi/naviGATR/docs/parallel_wheel_bringup.md) and
[Brain robot profiles](../pi/naviGATR/docs/brain_profile.md#calibration-and-stationary-handling)
describe the stationarity checks. The fixed axis does not compensate later
rocking, and the Brain's placement still supplies field heading. The IMU chip
(BNO08X or ASM330) is chosen by the Pico firmware build; a Brain profile only
selects Pico IMU port 0.

The Pi's `pico_imu_channel` converts yaw rate and accumulated rotation into radians,
then localization observation models estimate bias and use heading increments.
The protocol defines optional accel XY fields, but the current firmware does not
populate them: BNO08X acceleration is used internally for startup alignment.
No quaternion/roll/pitch report exists. See the
[attitude follow-up](../pi/naviGATR/docs/attitude_firmware_followup.md) for the
additional acquisition and protocol work needed for measured tilt.

The present estimator does not periodically correct robot heading from field
landmarks: landmark position estimation uses robot localization as an input.
The Brain link's gyro-fresh health bit reports sensor freshness, not an
implemented comparison between gyro and wheel-derived heading. Sensor specifications alone
do not establish assembled-robot drift or alignment accuracy.

## Tracking wheels

The [magnetic encoder board](../pcb/MagneticEncoder/README.md) supports compact
custom tracking-wheel assemblies using contactless magnetic rotation sensing.
The Pico counts A/B quadrature for three channels. Its
[pin map](../pico/aggreGATR/src/board.h) assigns channels to GP0/1, GP2/3, and GP4/5,
which are J2, J3 and J4 on the v2 HAT (logical encoder ports 0, 1 and 2); pin
and connector wiring must match the chosen HAT revision. The current bench has
a forward-measuring wheel on port 1 (J3) and a sideways wheel on port 0 (J2),
described on the Brain ([gatr2_robot.h](../brain/robot/gatr2_robot.h)); the
earlier two parallel wheels have their own
[XML bring-up](../pi/naviGATR/docs/parallel_wheel_bringup.md).

Counts per revolution, gearing and encoder polarity are sensor calibration.
Effective wheel radius, position, rolling direction and the measured travel
scale belong to the wheel model that turns wheel travel into body movement:
the Brain profile, or `wheel_geometry` in an XML profile. Verify the actual encoder
configuration and counted edges rather than assuming every assembly has the same
counts per revolution. The parallel-wheel AS5047P template uses its default
4000 counts/revolution with x4 decoding and direct 1:1 wheel coupling; see the
[bring-up guide](../pi/naviGATR/docs/parallel_wheel_bringup.md#3-fill-in-the-robot-description).
Unpowered tracking wheels measure ground movement but
still depend on contact, mounting rigidity, and calibration.

## Pi HAT

The [Pi HAT](../pcb/PiHat/README.md) mounts through the Pi's 40-pin header to reduce
loose wiring and provide a stable connection with dedicated sensor ports. The
family README compares iterations; each revision records its power arrangement,
regulator, peripheral connectors, and validation status.

The transceiver fitted to v2 was ST3485ECDR, although its saved schematic retains
the earlier THVD1410 selection. V3 records ST3485ECDR in its schematic. Use the
revision documentation when ordering or assembling rather than assuming all
boards share a BOM.

## Pico-to-Pi telemetry

The Pico sends sensor frames at 50 Hz on UART0 (Serial1), GP16 TX / GP17 RX,
115200 baud. The Pi profile selects the Linux device path. The current configs
use `/dev/ttyAMA0`; confirm the enabled UART and device mapping on the deployed
Pi. The [wire specification](interfaces.md) defines masks, integer units,
timestamps, and packet layouts.

The link is two way: the Pico also sends status frames (boot identity, epochs,
IMU state) and reads Pi commands (reinitialize the IMU, restart acquisition) on
GP17. See [Pico link](../pi/naviGATR/docs/pico_link.md). The Pi to Pico
direction on the HAT wiring has not been checked on hardware.

## USB to the V5 Brain

The current bench bypasses the HAT's RS-485 circuit: a data cable from a Pi
USB-A port to the Brain's micro-USB port, with the Brain on its V5 battery. The
Pi's `pros_usb_link` finds the Brain's USB user interface and wraps each frame
in an `NG1:` hexadecimal line; see
[USB bench](../pi/naviGATR/docs/usb_localization_bench.md). Choosing USB or
RS-485 needs the matching Pi config (`brain_profile_usb.xml` or
`brain_profile_rs485.xml`) and never changes localization geometry.

## RS-485 to the V5 Brain

The HAT routes Pi UART5 through a half-duplex transceiver:

| Signal | Pi GPIO | 40-pin header pin |
|---|---|---|
| UART5 TX to transceiver DI | 12 | 32 |
| UART5 RX from transceiver RO | 13 | 33 |
| Transceiver DE and /RE enable | 6 | 31 |

The enable line is pulled down on the board. With `<DriverEnable gpio="6"/>` the
Linux serial resource runs the link half duplex: it drives DE low at open so the
Pi listens, raises it only while it sends a reply, and drives it low again once
the UART reports its transmitter empty and a two-character guard has passed.
Errors and timeouts also release DE. The Brain is the only initiator and the Pi only
answers requests; the [interface spec](interfaces.md) defines bus ownership and
timing, and [navigatr resources](navigatr_resources.md#linux_serial_link) the
transmit sequence. The V5 smart port is assumed to switch its own RS-485
direction.

Hardware checks, not validated on the robot yet: the sysfs GPIO number (newer
kernels can offset it, for example 512 + 6), `TIOCSERGETLSR` and turnaround
timing on the Pi UART, DE behavior, and the V5 port's direction handling. If
the runtime is killed (SIGKILL, crash) while transmitting, DE stays high and
blocks the Brain until the runtime starts again and drives it low.

The [bench example](../bench/rs485_link/README.md) exercises Pi-to-Brain byte
transfer separately from the production codec. It does not validate command
return traffic. [Pi setup](pi_setup.md) covers access and UART provisioning.

## Camera and Pi runtime

The runtime targets a Raspberry Pi 4 and uses C++, libcamera, and the bundled
AprilRobotics detector. There is no Python/OpenCV localization process or EKF in
the current executable. The implemented planar estimator integrates configured
wheel-motion and heading observations.

Camera capture produces grayscale images for tag decoding. Intrinsics, detected
corner size, and rigid camera mounting are required for metric field estimates.
An uncalibrated inspection profile supports viewing images and decoded IDs first.
The browser renders the 3D field on the viewing computer, reached through an SSH
port forward to the Pi's inspection service.

See [camera setup](../pi/naviGATR/docs/pi_camera_setup.md) for supported capture
configuration and the remaining hardware checks. Pi throughput, capture timing,
memory use, and physical alignment accuracy have not been established by host
simulation tests. Measure them on the selected camera, mode, and robot.

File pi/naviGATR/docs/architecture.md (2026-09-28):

# Runtime architecture

Navigatr is one C++ executable. XML selects resource factories, sensor processors,
localization models, and the field/command/reporting implementations. The
[configuration guide](configuration.md) documents profile selection and file
composition; [resources](../../../docs/navigatr_resources.md) and
[sensors](../../../docs/navigatr_sensors.md) list registered implementations.

With a Brain-profiled configuration (`<BrainProfile>` under `Localization`,
the primary path) the XML names only the Pi's devices, wired ports and model
tuning. The localization models come from the robot profile the Brain sends,
built at runtime from typed data; see [Brain robot profiles](brain_profile.md)
and the section below.

## Construction

```text
main XML -> resolve referenced fragments -> System
  make_resources -> ResourceStore + ResourceExecutor
  make_sensors -> SensorExecutor
  CommandCollection factory
  make_localization -> LocalizationExecutor + RobotStateFeed
  make_world_estimation -> WorldEstimationExecutor
  TargetResolution factory
  Publishing factory
```

Each builder parses configuration once, resolves typed references, and captures
initialized state. `FunctionRegistry` maps implementation names to factories by
factory signature. Multiple instances can select the same type. A factory must
copy the configuration it needs; XML node views expire after construction.

`ResourceStore` owns initialized objects such as links, camera devices, detector
handles, and immutable geometry. Its bindings are frozen after construction.
Resources with runtime outputs also provide an executable and declarations of
those outputs. Static field definitions, robot frames, wheel geometry, target
sets, and transport handles can be bound directly without emitting measurements.

Every top-level Pipeline slot must be present: `CommandCollection`,
`Localization`, `WorldEstimation`, `TargetResolution`, and `Publishing`.
Localization selects observation functions and an estimator inside its own
subtree; WorldEstimation selects exactly one `Estimator` by `id` and `type`
inside its subtree. The other slots select an explicit `type`, including `noop`
when unused.
Duplicate IDs, unresolved references, incompatible payloads, and invalid geometry
fail construction. A partially built system is discarded.

## Resource and sensor execution

The coordinator invokes aggregate executors:

```cpp
const ResourceMap& resources = execute_resources_(context);
const SensorMap& sensors = execute_sensors_(resources, context);
robot_ = execute_localization_(sensors, requests, context);
```

The resource executor calls each configured acquisition executable once per
invocation. `ResourceMap[resource_id].outputs[output_id]` addresses a measurement,
including sources with only one output. A Pico telemetry resource drains and
decodes its link once, exposing configured encoder and gyro channels separately.

Each sensor receives the complete read-only ResourceMap and uses its captured
bindings. Sensors convert wire units, normalize electrical signs, apply sensor
mounting corrections, or forward an already usable sample. For example, the
encoder channel produces accumulated shaft angle; the localization observation
model applies wheel radius and placement to obtain robot displacement.

`SensorMap[sensor_id]` and resource outputs use `MeasurementRecord`:

- Source health and a diagnostic are separate from the retained latest sample.
- A sample carries typed data, measurement time, actual upstream receipt time,
  sequence, epoch, and provenance.
- A healthy poll without new data preserves the sample without advancing its
  sequence. Faults do not erase its history.
- Measurement time belongs to the declared source clock. Receipt time belongs to
  the host clock; forwarding a sample does not replace its receipt with poll time.

The maps are retained stage results, not owners of device handles. Consumers must
check health, freshness, and sequence rather than treating every read as new data.

## Localization

```text
SensorMap
  -> configured RobotObservationFunctions
  -> RobotObservationMap
  -> one StateEstimator
  -> settle accepted/rejected observations
  -> publish RobotState + localization status + history
```

Localization owns observation state, estimator state, and history. It provides
`RobotStateFeed` for synchronized snapshots and timestamped lookups. Localization
is the only writer; consumers use its snapshot and lookup operations.

Current observation implementations are:

| Type | Inputs and result |
|---|---|
| `tracking_wheel_motion` | Configured wheel geometry and encoder sensors, optionally a gyro heading constraint and an explicit zero-lateral-motion assumption for forward-only wheels; produces a body-motion increment over an interval. |
| `imu_heading_increment` | One IMU sensor and bias settings; produces a heading increment over an interval. |
| `attitude_reference` | One attitude sensor; produces a timestamped quaternion observation. |
| `brain_imu_planar_bench`, `brain_imu_parallel_bench` | Two wheels and the Brain VEX IMU mailbox (bench, arrival-time pairing); produces a body-motion increment whose rotation is the VEX IMU's. |

Three suitably placed tracking wheels can solve planar motion. Two wheels need
a heading constraint. Wheels that all measure forward, such as two parallel
wheels, also need `<LateralMotion assume="zero"/>`: sideways motion is then
assumed, not measured, and each wheel's travel is corrected by its lateral
lever arm times the gyro rotation. The model validates the geometry, aligns intervals, handles
source restarts, and does not bridge invalid spans. Gyro bias calibration belongs
to these observation models. Configuring the same gyro independently twice does
not create independent information: every sample carries the acquisition output
it came from (`Provenance.measurement`), and the estimators use that lineage,
not the configured sensor id, to detect overlapping contributors.

Every IMU bias path and the stationary status share one `StationaryWindow`
(`impl/localization/stationary_window.h`): new samples only, restarted by a
gap, a source restart or movement, qualified by elapsed sample time
(`window_ms`, 2 s unless configured, never zero). The
first qualified window gives the gyro bias; later ones maintain it in
bounded steps; a gyro restart invalidates it. While a window stays
qualified the executor reports zero velocity and the stationary health bit;
the pose is left alone. This is gated stationary handling, not a zero
velocity filter update: no estimator here models velocity with uncertainty.
See [Brain robot profiles](brain_profile.md#calibration-and-stationary-handling).

Observations remain pending until the estimator explicitly accepts or rejects
them. Functions receive the disposition through `settle`; this prevents a quiet
poll or retried observation from integrating the same movement twice. Payloads
are typed contracts, not arbitrary metadata that the estimator must interpret.

The implemented `planar_motion_integrator` selects one `BodyMotionIncrement`, an
optional `HeadingIncrement`, and an optional `AttitudeObservation`. A heading
supplies the rotation used for integration only when its support equals the
motion window exactly on one named clock; partial support from the window start
accumulates while the motion waits, bounded by `max_wait_ms`, and anything else
is rejected with the reason. The estimator checks measurement lineage overlap,
clock identity by name (a device domain alone identifies nothing), and
epoch continuity, integrates body motion into the previous odometry pose, and
derives velocity from displacement and elapsed time. These rules live in
`motion_step` and are shared with `weighted_planar_fusion`. It holds pose when no usable motion arrives. It is not a
multi-source statistical fusion filter and does not predict ahead using the
previous velocity. Another algorithm can implement the `StateEstimator` contract.

`weighted_planar_fusion` fills the same slot with an explicit uncertainty
model: configured one-sigma noise for the wheel increment and the gyro, a
precision-weighted rotation, translation re-solved through the wheel
geometry coupling the wheel model publishes, and a pose covariance
propagated with the heading-to-position coupling. Shared sources, interval
mismatches, repeated stamps and resets follow the integrator rules. See
[localization fusion](localization_fusion.md).

`RobotState` contains continuous odometry pose, a field anchor, velocity, yaw rate,
validity, effective measurement time, and separately timestamped attitude. Field
placement changes the anchor while preserving odometry. A hard reset changes the
odometry epoch. Only an advance in effective pose time enters pose history;
attitude has its own history so tilt updates do not invent new planar movement.
History lookup uses bounded storage, binary search, shortest-arc yaw interpolation,
and quaternion interpolation, with explicit age and gap failure results. Epoch
changes clear history, and association checks the returned odometry epoch.
See [coordinates](coordinates.md) for the transform and timing conventions.

## World estimation

```text
<WorldEstimation><Estimator id="goals" type="apriltag">...</Estimator></WorldEstimation>
  make_world_estimation -> WorldEstimationExecutor (one captured estimator)
  field_out = execute_world_({sensors, robot, history, previous_field, context})
```

The coordinator drives the selected estimator through one contract.
`FieldEstimationInput` carries the entire read-only `SensorMap`, the latest
`RobotState`, pose-history lookups, the previous `FieldState`, and the execution
context (host clock, invocation, diagnostics). `FieldEstimationOutput` carries
the updated `FieldState`, the observation and association maps the estimator
publishes, a status, and a diagnostic. The executor drops any observation or
association id the estimator never declared (or whose payload contradicts the
declaration) and records the run under `WorldEstimation/<id>` in the field
diagnostics. It never learns what steps run inside the estimator.

Exactly one `Estimator` is configured. `register_world_estimation` registers
`noop` (previous field carried forward, nothing published) and `apriltag`;
another selectable implementation needs its class, a registration line, and a
build entry, not a coordinator change.

The `apriltag` estimator privately owns a fixed serial subpipeline over one
camera, built from the field references it reads at construction:

```text
SensorMap -> ObservationExtraction (AprilTagObservationPerception) -> ObservationMap
          -> Association (TagMountAssociation, optional)          -> AssociationMap
          -> LandmarkEstimation (LandmarkEstimator)                -> FieldState
```

Observation extraction runs the detector over each new frame of the configured
camera. Association uses the exposure-time robot pose and attitude, camera
mount, configured tag mounts, and geometric gates to generate
`FieldObjectPoseEvidenceSet`; an optional trace retains candidate decisions for
inspection. Without an `Association` the decodes still publish (camera
inspection before the camera has a mount frame) and the landmark estimation
must be `commit="never"`. Payload types are checked when the estimator is
built; a step fault leaves the previous field untouched and publishes nothing.

Landmark estimation seeds all configured landmarks from the nominal field map.
With `commit="always"`, accepted evidence updates those objects; `commit="never"`
retains nominal/previous state while still publishing detections and associations.
The `blend` parameter controls interpolation from the previous estimate.
Observing a goal changes its estimate, not robot localization. World estimation
runs independently of whether a navigation target is requested.

`FieldSnapshot` contains FieldState, published observations/associations, timing,
and status. It is an immutable published snapshot. See
[landmarks](landmarks.md) for association, retention, and target/report semantics.

## Commands and publishing

Command collection produces `CommandState`: the current Brain session, the
newest placement (`init_pose`, `init_session`, `init_sequence`), the robot
profile status, the latest reported path, a target selection that only
in-process callers set (`object_requested`, `object_wire_id`,
`object_sequence`), and the reply owed for this cycle's request
(`BrainReplyContext`). Implementations are
`brain_link` and `noop`; `noop` keeps the Pi standalone on a bench.

The Brain talks to the Pi with the request/reply protocol in
[Brain link v4](../../../docs/interfaces.md): the Brain asks,
the Pi answers each request at most once, and nothing is sent unasked. The
`brain_link` pair implements the Pi side:

- `brain_link` command collection drains its serial link once per cycle,
  stamps every read with the link's microsecond clock, and processes only the
  newest request the drain completed. It owns the session rules: a random
  nonzero session per HELLO, a HELLO retry answered with the same session
  until another request is accepted, the last four opening nonces rejected as
  stale, per-session request_id dedupe with 16-bit wraparound, and SET_POSE
  and CONTROL records so a retry is answered, never applied twice. It
  also holds `pi_instance`, a random nonzero id that is new for every process
  start and every `reset()`. It computes the reply window from its read
  timestamps; see [Bus ownership and timing](../../../docs/interfaces.md#bus-ownership-and-timing).
- A new session clears only client state: the dedupe records, the bench IMU
  mailbox and the reported path. It never touches `init_*`, localization,
  the profile or the field documents, so a new session alone never relocates
  the robot.
- `System::requestsFrom` passes the command placement to localization only
  while `init_session` equals the current session, so a new session withdraws
  a placement not applied yet. `PlacementEdge` applies a placement once per
  (origin, session, sequence) and records that identity in `RobotState`
  (`placement_origin` `command` or `configuration`, `placement_session`,
  `placement_sequence`). A configured `InitialPlacement` is
  (`configuration`, 0, 1).
- With a Brain profile host, PROFILE_WRITE stages the profile, PROFILE_APPLY
  hands it to the System, CONTROL (recalibrate, reinitialize, Pico IMU
  reinit, acquisition restart) and READ_WHEELS go to the running profile,
  and SET_POSE is NotReady until a profile runs. PATH_REPORT is stored for
  inspection only.
- `brain_link` publishing writes only when the command slot left a reply
  pending, once, through the link's windowed write. SET_POSE is `Ok` only
  when `RobotState` reports that exact placement applied, otherwise
  `Pending`. GET_STATE carries the robot pose and flags, the robot
  measurement age, health bits, the profile status, and the ids of the
  current field documents. With a `Field`, READ_DOC serves the field map
  and field estimate documents in chunks: every configured object, nominal
  or observed (see [landmarks](landmarks.md#field-documents)).

Construction enforces the pairing: `brain_link` command collection needs
`brain_link` publishing, and that publisher needs `brain_link` command
collection on the same `Serial` resource. A profile with `brain_link`
command collection must also satisfy `1000 / Loop rate_hz <= window_ms / 2`.
The factories read the loop rate, the command type and its serial resource,
and the Brain profile host from `SlotInitializationContext`.
Publishing receives the diagnostics through `PublishingInput` and counts its
writes in the link's `LinkStats`.

A `linux_serial_link` with `DriverEnable` runs RS-485 half duplex: it listens
while idle and drives the transceiver only while sending a reply, releasing it
once the transmitter is empty. The sequence is in `transport/half_duplex` over
a small port interface; see [linux_serial_link](../../../docs/navigatr_resources.md#linux_serial_link).

## Brain robot profiles

A Brain-profiled System starts waiting: noop localization, while resources,
the Brain link, world estimation, publishing and inspection run. On
PROFILE_APPLY the System checks this Pi's capabilities, writes Sensors and
Localization subtrees from fixed Pi templates (ids generated on the Pi; the
Brain never sends XML) and builds the candidate at once through the ordinary
factories, touching nothing that runs. The swap happens at a controlled
boundary in the `reset()` pattern: the main thread calls
`applyPendingProfile()` every 20 ms in worker mode (workers stop, the
candidate moves in, workers restart), and `step()` does it first inline. The
resources, the commands slot with its session and `pi_instance`, world
estimation, publishing, the feed and inspection survive. A new profile
advances the odometry epoch, clears history, leaves the robot unplaced and
withdraws every earlier placement request; re-applying the running profile
changes nothing. Inspection reads the running binding through one immutable
`BindingView`.

Every cycle the sources the running profile uses are watched
(`runtime/sensor_loss.h`): its encoders, and the Pico IMU or the Brain VEX
IMU mailbox when the profile uses one. A used source that is stale longer
than `sensor_loss_ms`, restarts, or (Pico IMU) reports itself not ready ends
pose continuity like a new profile does, and the Brain must place again.
After localization runs, the same happens when an observation function
reports a new dropped interval (`ObservationReadiness::dropped_intervals`):
measured motion it had to discard, such as a gap past its own limit or
movement while its gyro bias calibrated.
With `<Pico resource_id>` on the CommandCollection, CONTROL 3 and 4 run on the
Pico through the `PicoControl` contract. Lifecycle events go to a bounded log
that inspection shows. Details: [Brain robot profiles](brain_profile.md).

## Targets

`configured_targets` resolves targets from `target_set`. It can latch a desired
robot pose from a relative movement, a landmark estimate, or an `acquire_once`
visual acquisition. A selection activates the target with that target
`wire_id`; brain link v4 has no selection op, so only in-process callers
select today. Targets are Pi internal: inspection shows
them, the brain link never sends them. This stage owns target lifecycle; it
does not alter the field estimate. The Brain remains responsible for motor
control.

## Scheduling and lifecycle

Default execution uses two workers:

1. The estimation worker polls resources and sensors, collects commands, updates
   localization, and runs target resolution/publishing against the newest field
   snapshot. It hands a copied SensorMap to the field worker through a bounded,
   latest-wins mailbox.
2. The field worker runs world estimation on the latest available sensor
   snapshot and publishes its result. Slow detection can skip intermediate
   snapshots without blocking the estimation worker.

Resource acquisition is still invoked from the estimation worker. The libcamera
backend receives camera requests asynchronously and exposes the newest frame;
there is no generic worker per resource or sensor. A newly added blocking resource
can therefore slow localization.

A Brain request is read by command collection and answered by publishing in
the same estimation cycle, from that cycle's robot state and the newest
completed field snapshot, so a reply never waits for camera processing. The
reply write blocks the estimation worker for about the frame airtime: up to
11.1 ms for a 128-byte reply at 115200 baud, about 13 ms with the transmit
margin. Over USB the write waits at most 5 ms of backpressure.

`--inline` runs estimation, field estimation, and reporting serially for replay
and tests. Field estimation then runs between the Brain request and its reply,
so the brain link needs the default threaded mode; the executable warns when
`--inline` is used with it. The optional inspection service reads published
snapshots at its own rate, serving JSON and JPEG previews over loopback
HTTP/WebSocket. Slow clients are skipped rather than stalling an estimator.

`stop()` joins workers before their dependencies are destroyed. `reset()` stops
workers, resets stages and shared resources, changes history/source epochs, clears
published state, and resumes workers when appropriate. For the brain link it
draws a new `pi_instance`, forgets the Brain session, and clears `CommandState`
(`init_sequence` restarts at 0); the Brain sees the new `pi_instance` and opens
a new session. A Brain-profiled System returns to waiting for a profile.
Snapshot readers use synchronized copies; inspection never calls mutable
estimator implementations.

## Source map

| Area | Source |
|---|---|
| Coordinator and workers | [system.cpp](../src/runtime/system.cpp) |
| Resource/sensor executors | [resource_stage.cpp](../src/runtime/resource_stage.cpp), [sensor_stage.cpp](../src/runtime/sensor_stage.cpp) |
| Localization executor | [localization_stage.cpp](../src/runtime/localization_stage.cpp) |
| Localization contracts and payloads | [localization.h](../src/contracts/localization.h), [robot_observations.h](../src/payloads/robot_observations.h) |
| State estimators | [planar_motion_integrator.cpp](../src/impl/localization/planar_motion_integrator.cpp), [weighted_planar_fusion.cpp](../src/impl/localization/weighted_planar_fusion.cpp) |
| World estimation executor | [world_estimation_stage.cpp](../src/runtime/world_estimation_stage.cpp) |
| AprilTag world estimator | [apriltag_world_estimator.cpp](../src/impl/world_estimation/apriltag_world_estimator.cpp) |
| Target lifecycle | [configured_targets.cpp](../src/impl/target_resolution/configured_targets.cpp) |
| Brain requests and sessions | [brain_link_commands.cpp](../src/impl/commands/brain_link_commands.cpp), [command_state.h](../src/state/command_state.h) |
| Brain replies | [brain_link_publisher.cpp](../src/impl/publishing/brain_link_publisher.cpp) |
| Field documents | [field_documents.cpp](../src/impl/publishing/field_documents.cpp) |
| Brain profile templates and checks | [brain_profile_builder.cpp](../src/runtime/brain_profile_builder.cpp) |
| Stationary window and gyro bias | [stationary_window.cpp](../src/impl/localization/stationary_window.cpp) |
| Sensor loss and stationary precheck | [sensor_loss.cpp](../src/runtime/sensor_loss.cpp), [stationary_precheck.cpp](../src/runtime/stationary_precheck.cpp) |
| Inspection documents | [inspection_document.cpp](../src/inspection/inspection_document.cpp) |
| Half-duplex transmit | [half_duplex.cpp](../src/transport/half_duplex.cpp), [serial_port.cpp](../src/transport/serial_port.cpp) |

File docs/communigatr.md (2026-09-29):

# communiGATR

`brain/communiGATR` is the Brain side of the Pi link, brain link v4
([interfaces.md](interfaces.md#brain-link-v4)). It:

- opens and keeps a session with the Pi over USB or RS-485;
- uploads the Brain's robot profile and follows its application;
- reads the field map and field estimates in chunks and publishes them whole;
- gives planning and control the robot state and the field as an
  `investigatr::StateSource`, and forwards planned paths to the Pi viewer;
- places the robot, runs calibration and recovery actions on the Pi, and reads
  raw wheel travel for calibration;
- sends best-effort telemetry (VEX IMU tilt, movement status, wheel targets)
  for the Pi viewer and recordings;
- sums up what the link, profile, sensors, calibration and placement still
  wait for.

It does not plan routes ([investiGATR](investigatr.md)) or drive motors
([actuGATR](actugatr.md)). Robot setup, calibration procedures and the two
test programs are in [Brain setup](brain_setup.md).

Status: host tested against a fake Pi over a simulated RS-485 bus and a
simulated USB console. The PROS sources (`pros/`) compile only in the PROS
build. Nothing here has been validated on the robot, on the V5 USB console or
on real RS-485 hardware.

| Path | Contents |
|---|---|
| `include/communigatr/` | public headers; `pros_*.h` are PROS only |
| `src/` | portable sources, host and PROS |
| `pros/` | PROS only sources, never built on the host |
| `sim/` | host only fake Pi, RS-485 bus, USB console and test rig |
| `tests/` | host tests |

Namespace `communigatr`. Time is `Seconds` (double) everywhere; the portable
classes take the time as an argument and have no clock, thread or PROS
dependency.

## Layers

```
application (locaGATR, testing)
  actugatr::Motion, planner      use StateSource and PathSink only
  ProsLink                       PROS: poll task, bounded mutex, either transport
    LinkDriver                   StateSource + PathSink: SI units, status, frames, field
      Client                     protocol: session, scheduling, retries, profile,
                                 documents, placement, control, wheels, path,
                                 telemetry
        BytePort                 nonblocking bytes
          ProsUsbPort            V5 USB user console, NG1 lines, two I/O tasks
          ProsSerialPort         V5 smart port, generic serial, RS-485 adapter
  ProsVexImu                     Brain VEX IMU sample carried by GET_STATE, and
                                 roll and pitch for TELEMETRY
```

| Class or function | Header | Portable | Role |
|---|---|---|---|
| `BytePort` | `byte_port.h` | yes | nonblocking `read`/`write` interface |
| `Client` | `client.h` | yes | brain link v4 state machine; all I/O in `poll(now)` |
| `LinkDriver` | `link_driver.h` | yes | `StateSource` and `PathSink` over a client; no I/O |
| `RobotProfile`, `makeProfileDocument` | `robot_profile.h` | yes | robot profile in SI units, wire document, shared check |
| `DocAssembly` | `doc_assembly.h` | yes | one READ_DOC document, bounded and checked |
| `readinessOf`, `Readiness` | `readiness.h` | yes | readiness summary and decoded health |
| `encodeUsbLine`, `UsbLineDecoder` | `usb_line.h` | yes | NG1 line codec |
| `VexImuRecalibration` | `vex_imu_recalibration.h` | yes | Brain VEX IMU calibration gated by the Pi's stationary check |
| `robotAttitudeFromVex`, `setAttitude` | `attitude.h` | yes | VEX IMU roll and pitch to the robot frame; TELEMETRY attitude group |
| `WheelCalibration` | `wheel_calibration.h` | yes | per-wheel travel scale trials (application helper) |
| `StartupPlacement` | `startup_placement.h` | yes | once-per-start placement policy (application helper) |
| `LinkEvents` | `link_events.h` | yes | recovery history for displays (application helper) |
| `ProsLink` | `pros_link.h` | PROS | owns port, client and driver; poll task; both transports |
| `ProsUsbPort` | `pros_usb_port.h` | PROS | `BytePort` over the V5 USB console |
| `ProsSerialPort` | `pros_serial_port.h` | PROS | `BytePort` over a smart port in generic serial mode |
| `ProsVexImu` | `pros_vex_imu.h` | PROS | VEX IMU as the Brain bench IMU source |

## PROS use

A program creates one `ProsLink` and keeps it for its whole run. This is what
both test programs do, with the robot description from
[brain/robot/gatr2_robot.h](../brain/robot/gatr2_robot.h):

```cpp
#include "communigatr/pros_link.h"
#include "communigatr/pros_vex_imu.h"
#include "gatr2_robot.h"

std::unique_ptr<communigatr::ProsVexImu> g_vex;  // kept for the program's life
std::unique_ptr<communigatr::ProsLink>   g_link;

void initialize() {
    communigatr::LinkConfig config;
    if (gatr2_robot::kUseUsb) {
        config.transport = communigatr::Transport::kUsb;
    } else {
        config.transport  = communigatr::Transport::kSmartPort;
        config.smart_port = gatr2_robot::kLinkPort;
        config.baud       = gatr2_robot::kLinkBaud;
    }
    config.profile = gatr2_robot::profile();          // RobotProfile, SI units
    if (gatr2_robot::usesVexImu()) {
        g_vex.reset(new communigatr::ProsVexImu(gatr2_robot::kVexImuPort));
        communigatr::ProsVexImu* vex = g_vex.get();
        config.client.bench_imu      = [vex] { return vex->sample(); };
    }
    g_link.reset(new communigatr::ProsLink(config));
    g_link->start();  // false: task not created (errno set); call again later
}

// Any task, every loop:
//   const communigatr::ProsLinkStatus s = g_link->status();   // readiness, profile, stats
//   const investigatr::RobotState r = g_link->robot(communigatr::ProsLink::now());
//   if (r.valid()) { ... r.pose, r.age, r.frame ... }
```

- `start()` only creates the poll task. The task opens the transport and
  reopens it while it is closed; nothing in `initialize()` waits for the Pi.
- Pass `ProsLink::now()` (seconds since PROS start, from `pros::micros()`) to
  `robot()` and to every controller that uses the link. Ages and link timing
  are only meaningful on that clock.
- actuGATR's `Motion` takes the `ProsLink` as its `StateSource` and
  `PathSink` ([actuGATR](actugatr.md)).
- The planner and the robot state never depend on the VEX IMU: `ProsVexImu`
  only feeds the GET_STATE sample, and only for a profile whose IMU source is
  the Brain VEX IMU.

### LinkConfig

| Field | Default | Meaning |
|---|---|---|
| `transport` | `kUsb` | `kUsb`: V5 USB user console. `kSmartPort`: RS-485 adapter on a smart port |
| `smart_port` | 0 | `kSmartPort` only: V5 port 1..21 |
| `baud` | 115200 | `kSmartPort` only: must match the Pi serial resource |
| `poll_period_ms` | 2 | poll task period, at least 1 |
| `task_priority` | `TASK_PRIORITY_DEFAULT + 1` | poll task priority |
| `call_timeout_ms` | 20 | bounded mutex wait of every public call |
| `profile` | empty | `RobotProfile` to upload; when set it replaces `client.profile`. Empty and no `client.profile`: the Pi runs its own XML localization |
| `client` | `ClientConfig{}` | see [ClientConfig](#clientconfig); `bench_imu` runs in the poll task under the link mutex |
| `driver` | `LinkDriverConfig{}` | `accept_configured_anchor`, see [Robot state](#robot-state) |

The transport choice is explicit and has a matching Pi configuration:
`brain_profile_usb.xml` (`pros_usb_link`) for USB and `brain_profile_rs485.xml`
(`linux_serial_link`) for RS-485. There is no automatic choice or failover.
The transport never changes the robot profile or the localization.

### ProsLink calls

Every call takes the link mutex with a bounded wait (`call_timeout_ms`) and
copies values out. When the mutex is busy the call gives a safe answer and
counts it in `status().link.call_lock_misses`.

| Call | Effect | Busy answer |
|---|---|---|
| `start()` | create the poll task; true once started | |
| `now()` (static) | poll task clock, seconds | |
| `status()` | `ProsLinkStatus`, below | `busy` true; only `started`, `transport`, `port_open`, `link` and `usb` current |
| `robot(now)` | `investigatr::RobotState` | status `kNoLink` |
| `field(out)` | copy the newest complete field into `out` unless it already holds that generation | `out` unchanged; true when it holds a field |
| `reportPath(command, path)` | planned path to the Pi viewer, best effort | dropped |
| `place(pose)` | SET_POSE ticket, 0 when refused | 0 |
| `placement(ticket)` | `PlacementStatus` | `kPending` for a nonzero ticket (ask again) |
| `recalibrate()`, `reinitialize()`, `reinitImu()`, `restartAcquisition()` | CONTROL ticket, 0 when refused | 0 |
| `control(ticket)` | `ControlStatus` | `kPending` for a nonzero ticket |
| `requestWheels()` | READ_WHEELS ticket, 0 when refused (no session, another read pending) | 0 |
| `wheels(ticket)` | `WheelStatus` with the readings | `kPending` for a nonzero ticket |
| `wheelReadings()` | readings of the latest Ok reply of any read, by value | `busy` set, sequence 0, result NotReady |
| `setProfile(profile)` | replace the configured profile at run time | false |
| `profile()` | the configured `RobotProfile` | empty profile |
| `resubmitProfile()` | upload and apply again, clearing a settled rejection | false |
| `reportTelemetry(t)` | TELEMETRY for the Pi viewer, best effort, see [Telemetry](#telemetry) | dropped, false |

### ProsLinkStatus

| Field | Meaning |
|---|---|
| `busy` | the mutex was not taken in time; the fields below `port_open` are not current |
| `started`, `transport`, `port_open` | poll task running, selected transport, port open |
| `ready`, `connected`, `link_age` | session with a state reply; a reply within `link_timeout`; time since the last reply (infinity without a session) |
| `session`, `pi_instance`, `error`, `peer_version` | current session, Pi instance, last incompatibility and the Pi's version |
| `readiness`, `summary` | [readiness](#readiness) state and its details (IMU use, decoded health, calibration, Brain IMU calibrating, localized, pose valid) |
| `profile` | `ProfileStatus`: sync state, id, reason, detail, last result, bytes the Pi holds |
| `state` | latest GET_STATE Ok of this session, raw wire units |
| `telemetry_unsupported` | the Pi refused TELEMETRY in this session (an older Pi); nothing more is sent until a new session |
| `heading_valid`, `heading` | raw Pi heading, placed or not, while the Pi has a pose; used by wheel calibration |
| `field_sync` | transfer progress: complete map id, map bytes read, estimate id being read |
| `field_generation`, `map_id`, `estimate_id`, `field_age` | published field and time since its estimate completed |
| `stats`, `link`, `usb` | `ClientStats`, `ProsLinkStats`, `ProsUsbStats` counters |

`ProsLinkStats`: `poll_lock_misses` (poll cycles skipped), `call_lock_misses`
(busy answers), `opens` (transport open attempts), `serial_closes` (smart
port closed after repeated errors).

### Tasks and locks

| Task | Priority | Role |
|---|---|---|
| `communigatr` | `task_priority` | opens and reopens the transport, then `client.poll(now)` under the mutex every `poll_period_ms` |
| `communigatr-usb-tx` | `TASK_PRIORITY_DEFAULT` | USB only: writes NG1 lines |
| `communigatr-usb-rx` | `TASK_PRIORITY_DEFAULT` | USB only: reads stdin, decodes lines |

- Each poll cycle takes the mutex with a wait of one period. A miss skips
  the cycle and counts in `poll_lock_misses`.
- Opening runs outside the mutex: only the poll task touches the port, and a
  smart port open may wait about 100 ms for the port to settle.
- PROS deletes competition tasks (autonomous, opcontrol) at mode changes
  without releasing mutexes they hold. Because every wait is bounded, a
  deleted holder costs skipped cycles and busy answers, all counted, but the
  link cannot recover until the program restarts. Run loops that call the
  link in your own tasks, as both test programs do.
- `std::shared_ptr` is not shared between tasks: the PROS toolchain has no
  atomic reference counts. `ProsLink` hands out value copies only.
- The destructor stops the poll task within 250 ms and deletes it only as a
  last resort. Keep a started link for the program's life.

### HELLO nonce

The client asks for a nonce once per new HELLO. `ProsLink` mixes, with a
murmur3 finalizer, `pros::micros()` at construction, at `start()`, at each
transport open and at the call; battery voltage and current; an object and a
stack address; and a call counter. The nonce only has to differ from the Pi's
last four opening nonces. A collision costs one `kResultStale` and a new
nonce; a 0 or a repeat is replaced by the client.

## Transports

`BytePort` is the seam: `read` returns what is waiting (0 none, negative on
error) and `write` queues a whole frame or nothing. Neither blocks.

### USB (`ProsUsbPort`)

Each link frame travels as one NG1 line, `"NG1:" + uppercase hex + "\n"`
([USB NG1 envelope](interfaces.md#usb-ng1-envelope)). The line codec
(`usb_line.h`) is portable and follows the Pi's `pros_usb_link` parser: the
last marker in a line counts, text before it is ignored, a trailing `\r` is
stripped, the digits are uppercase, even in number and 2..256 long, and any
fault drops the whole line. A line longer than 516 characters is dropped.

- `open()` opens the PROS named stream `/ser/ngtr`, activates it, disables
  PROS output COBS, and starts whichever I/O task is not running. Any failed
  step returns false (errno set) and is retried by the poll task.
- COBS off applies to all PROS output in the program, so console text
  (`printf`) arrives plain and the Pi skips it. Each NG1 line is written with
  one call, which the kernel keeps whole between other console output.
- Input comes from stdin. Kernel 4.2.2 appends a NUL after the data it
  returns, so one byte of the read buffer stays free.
- The client's `write` only pushes onto a one-slot queue; a full slot is a
  failed attempt that the client counts. Decoded frames wait in a four-slot
  queue. Both queues are lock-free, one producer and one consumer.
- A queued frame older than `clamp(response_timeout * 800, 1, 10000)` ms (48
  ms by default) is dropped unwritten, so a stalled writer never replays an
  expired request.
- `SERCTL_NOBLKWRITE` has no effect in kernel 4.2.2, and USB writes can block
  while no host is reading. Only the transmit task makes USB calls, so a
  blocked write stalls that task alone: the poll task, the program and
  battery-only operation carry on. Program `printf` calls may still block the
  task that makes them while no host reads; keep console output low or off.
- The port stays open across unplugging; the Brain sees timeouts until the
  cable is back. The Pi reopens its device at most once a second and does
  not answer the first request after reopening (it still applies it); the
  next request, a resend or a new poll, gets an answer.

### RS-485 (`ProsSerialPort`)

- `open()` enables generic serial on the smart port, then sets the baud and
  flushes, retrying every 2 ms for up to 100 ms while the port settles. It
  returns false when PROS refuses, and can be called again.
- `read` returns only bytes already received. `write` is all or nothing: the
  whole frame must fit the output FIFO, else it is refused (not an error).
- After 50 consecutive read or write errors the port counts as closed
  (`serial_closes`), and the poll task reopens it at most once a second.
- The V5 smart port is assumed to switch its own RS-485 direction. Not
  validated.

## Robot profile

The Brain owns the robot's localization description and sends it to the Pi as
a typed document; the Pi never receives XML or file paths
([Robot profile exchange](interfaces.md#robot-profile-exchange)).

```cpp
#include "communigatr/robot_profile.h"

communigatr::TrackingWheel forward;
forward.encoder_port   = 1;        // naviGATR encoder port: 0 J2, 1 J3, 2 J4
forward.radius         = 0.024;    // PROVISIONAL
forward.counts_per_rev = 4000;     // encoder shaft
forward.x = 0.0; forward.y = 0.15; // contact point, robot frame (PLACEHOLDER)
forward.angle          = 0.0;      // measures forward travel

communigatr::TrackingWheel sideways = forward;
sideways.encoder_port = 0;
sideways.x = 0.15; sideways.y = 0.0;   // PLACEHOLDER
sideways.angle = investigatr::kPi / 2; // measures leftward travel

communigatr::RobotProfile p;
p.topology       = communigatr::LocalizationTopology::kTwoWheelImu;
p.wheels         = {forward, sideways};
p.imu_source     = communigatr::ImuSource::kBrainVex;
p.vex_smart_port = 20;
p.footprint      = {0.23, 0.23, 0.23, 0.23}; // front, back, left, right (PLACEHOLDER)
```

This example demonstrates the profile format with placeholder geometry. The
current robot's values live in `gatr2_robot.h`
([Where settings live](brain_setup.md#1-where-settings-live)).

### Fields

| `RobotProfile` | Wire | Rule |
|---|---|---|
| `topology` | topology | see the table below |
| `wheels` | wheel records | 2 or 3 by topology |
| `imu_source` | imu_source | `kNone`, `kPico`, `kBrainVex` |
| `imu_port` | imu_port | Pico IMU port with `kPico` (0 on HAT v2), else 0 |
| `vex_smart_port` | vex_smart_port | 1..21 with `kBrainVex`, else 0 |
| `imu_invert` | imu_flags bit 0 | `kPico` only: Pico yaw sign flipped |
| `calibration.window` | calibration_window_ms | Pi IMU bias stationary window; 0 = Pi default, else 0.5..20 s |
| `calibration.still_rate` | still_rate_cdps | gyro rate still counted as still, rad/s; 0 = default, else 0.1..20 deg/s |
| `calibration.still_travel` | still_travel_um | per-wheel travel still counted as still over the window; 0 = default, else 20..5000 um |
| `footprint` | footprint_*_um | distance from the origin to each side, 0..2 m, nonzero length and width |
| `cameras` | camera records | up to 4, distinct Pi camera slots, mount within 2 m and 360 deg |

| `TrackingWheel` | Wire | Rule | Kind |
|---|---|---|---|
| `encoder_port` | encoder_port | distinct per wheel; the Pi checks it is wired | encoder |
| `counts_per_rev` | counts_per_rev | encoder shaft counts, 1..1000000 | encoder |
| `reversed` | flags bit 0 | encoder polarity: positive counts mean travel against `angle` | encoder |
| `gear_ratio` | gear_micro | encoder turns per wheel turn, 0.1..10 | encoder |
| `radius` | radius_um | 1..200 mm | geometry |
| `x`, `y` | x_um, y_um | contact point, robot frame, within 1 m | geometry |
| `angle` | angle_mdeg | measuring direction, CCW from +x, within 360 deg | geometry |
| `travel_scale` | travel_scale_ppm | measured distance correction, 0.9..1.1; 1.0 uncalibrated | empirical |

The Pi applies each kind once: counts per revolution, gearing and polarity in
the encoder sensor; radius and direction in the observation model; the travel
scale as a factor on that travel. A measured travel test sees only the product
of radius, gearing and travel scale, so keep radius and gearing physical and
put the measured correction in `travel_scale`; its range is narrow on purpose.

| Topology | Wheels | IMU source | Observability |
|---|---|---|---|
| `kTwoWheelImu` | 2 | `kPico` or `kBrainVex` | independent directions |
| `kTwoForwardWheelImu` | 2 | `kPico` or `kBrainVex` | both angles 0 or 180 deg; no sideways travel assumed |
| `kThreeWheel` | 3 | `kNone` or `kPico` | the three wheels resolve x, y and rotation |

A Brain VEX IMU with three wheels is refused (`ImuCombination`): its samples
run on the Brain clock and cannot be fused as an independent observation. The
Pico IMU chip (BNO08X or ASM330) is fixed by the Pico firmware build;
`kPico` only selects the Pico IMU port.
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

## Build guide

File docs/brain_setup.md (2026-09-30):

# Brain setup, calibration and tests

This guide covers how to configure, build, calibrate and test the robot from
the Brain:

- The Brain describes the robot: tracking wheels, encoders, IMU source, footprint, start pose, drivetrain and gains. It sends that description to the Pi as the robot profile each time it connects.
- The Pi owns its devices (serial ports, cameras, the field definition).
- The Pico owns pins and sensor drivers.

Changing the robot's geometry or tuning means editing Brain C++ and uploading;
no Pi XML changes.

Nothing in this guide has been validated on the robot yet. The host test suites
check the software, not the hardware.

## 1. Where settings live

| What | File |
|---|---|
| Tracking wheels: encoder port, counts per revolution, polarity, gearing, radius, mounting position, measuring direction, travel scale | [brain/robot/gatr2_robot.h](../brain/robot/gatr2_robot.h) |
| Localization setup (two wheels + VEX IMU, two wheels + Pico IMU, three wheels + Pico IMU) | `gatr2_robot.h`, `kSetup` |
| IMU source, VEX Smart Port, IMU calibration settings | `gatr2_robot.h` |
| Telemetry to the Pi viewer on or off, its period, the VEX IMU mounting for the viewer's tilt | `gatr2_robot.h`, `kSendTelemetry`, `kTelemetryPeriodMs`, `kVexImuMountYawDeg` (section 10) |
| Robot footprint, start pose | `gatr2_robot.h` |
| Pi link: USB or RS-485 (Smart Port, baud) | `gatr2_robot.h`, `kUseUsb` |
| Drivetrain (tank or mecanum): motor ports, reversal, cartridge, gearing, wheel size, track and wheelbase | [brain/operaGATR/include/robot_config.h](../brain/operaGATR/include/robot_config.h) |
| Speed limits, clearance, follower gains, manual speeds, test destinations, startup placement | `brain/operaGATR/include/robot_config.h` |
| Bench settings: startup placement policy, calibration reference distance and limits | [brain/locaGATR/include/robot_config.h](../brain/locaGATR/include/robot_config.h) |
| Pi devices, field, cameras, service | the Pi config, `pi/naviGATR/config/override/brain_profile_usb.xml` or `brain_profile_rs485.xml` |
| Pico pins and IMU driver | `pico/aggreGATR/src/board.h`, the PlatformIO environment |

Values marked UNMEASURED or PLACEHOLDER are guesses; measure them before
trusting the results. The tracking wheel radius, 0.024 m, is provisional.

**Current bench setup**
- Encoder port 0 (J2) measures sideways travel and port 1 (J3) measures forward travel; port 2 (J4) is unused.
- The VEX IMU is on Smart Port 20.
- The Brain talks to the Pi over USB.

The program checks port conflicts: drive motors, the VEX IMU and the RS-485 port must all be different. With a conflict the drive program refuses to create its motors and says why on the screen.

### Switching setups

- **External Pico IMU:** set `kSetup = Setup::kTwoWheelPicoImu`. The Pico firmware decides which chip (BNO08X or ASM330); the profile only selects the Pico IMU port.
- **Three tracking wheels:** set `kSetup = Setup::kThreeWheelPicoImu`, then fill in `leftWheel()` and `rightWheel()`. The Pi fuses the three wheels with the Pico IMU. A three-wheel setup with the VEX IMU is refused, because the VEX IMU runs on the Brain's clock.
- **RS-485:** set `kUseUsb = false` and `kLinkPort`, and run the Pi's `brain_profile_rs485.xml` config. The Pi must run the matching transport config; this is the one setting that is not Brain only.
- **An older XML-configured Pi config** (`bench_vex_imu*.xml`, `parallel_wheels*.xml`, the three-wheel templates): set `kSendProfile = false`. These configs refuse a Brain profile, and with one configured the Brain would never place the robot. Their XML then owns the geometry, and the wheel calibration apply step is not available.
- **Mecanum:** set `kDrivetrain = Drivetrain::kMecanum` in the testing `robot_config.h`, and fill in `mecanum()`.

## 2. Build and upload

**Brain (Windows, PROS CLI from the VS Code PROS extension terminal).** The first time, in each program folder:

```sh
cd brain/locaGATR
pros c apply kernel@4.2.2 --force-apply --no-download
git checkout -- .gitignore
```

Then build and upload:

```sh
pros make
pros upload --slot 2 --name locaGATR --after screen
```

The drive program goes in its own slot:

```sh
cd brain/operaGATR
pros make
pros upload --slot 1 --name operaGATR --after screen
```

**Pi (Raspberry Pi OS).** Copy the source from Windows, build and install the service. See [Pi setup](pi_setup.md) for access and the copy step. On the Pi:

```sh
cd ~/GATR2-Electronics/pi/naviGATR
cmake -S . -B build-bench -DCMAKE_BUILD_TYPE=Release -DNAVIGATR_BUILD_TESTS=OFF -DNAVIGATR_WITH_LIBCAMERA=OFF
cmake --build build-bench -j2
sudo bash tools/install_service.sh --user "$USER" --binary build-bench/navigatr --config config/override/brain_profile_usb.xml
```

**Pico (PlatformIO, Windows or Linux).** Build, then flash when the Pico is connected over USB:

```sh
cd pico/aggreGATR
pio run -e hat2_bno08x                 # or -e hat2_asm330
pio run -e hat2_bno08x -t upload       # flashes the Pico
```

The Pi and the Brain work with the older Pico firmware too, but only the new firmware reports its boot identity and takes Pi commands (IMU reinitialize, acquisition restart). Without it, the Pi falls back to detecting reboots from the clock and those commands fail with "Pico link".

**Update order:** the new Pico firmware sends only the new sensor frame, which older Pi software ignores (no encoder data). Build and restart the Pi service first, then flash the Pico.

## 3. Localization test program

`locaGATR` never drives motors. Move the robot by hand.

**Startup**
1. Start the Pi service and the program, with the robot still.
2. The program connects over the configured link and sends the robot profile. The Pi checks and applies it; the screen shows the profile id, or the reason for a rejection.
3. **Hold still while the sensors start.**
   - With the VEX IMU, the Brain calibrates it (about 2 s).
   - With the Pico IMU, the Pico aligns to gravity (about 2 s level and still), then the Pi measures the gyro bias over a still window (2 s by default).
4. Once the link, profile and sensors are ready, the program places the robot at `kStartPose`, **once per program start**. If that takes longer than `kStartupWaitSeconds` (90 s, enough for a cold Pi boot), it gives up and you place explicitly. It never places the robot on its own again.

**Pages** (B, or the right screen button, cycles)

| Page | Controls |
|---|---|
| Status | pose, readiness, sensors, calibration, and with the VEX IMU its robot-frame tilt (`r`, `p`, section 10). A places at the start pose. X recalibrates the IMU. Y reinitializes the Pico IMU. Hold L1+R1 and press A to reinitialize localization. |
| Wheel calibration | see section 4 |
| Recovery | the last link, session, Pi, Pico and calibration events, with times and outage lengths |

**Readiness line**
- Connecting, reconnecting.
- Profile pending, profile rejected (with the reason).
- Sensors unavailable, sensors initializing.
- Waiting for stillness, calibrating.
- Needs placement.
- Ready.

A pose is **LIVE** when it is connected, placed and no older than 0.25 s.

**Viewer:** the browser viewer on the Pi shows the same pose with the field, its obstacle boxes, the robot footprint from the profile, and a calibration and recovery panel, all without a camera. From your computer run `ssh -N -L 8765:127.0.0.1:8765 <user>@<pi-host>`, then open `http://127.0.0.1:8765/`.

## 4. Per-wheel calibration

**What it measures and what it does not**

The wheel travel the Pi reports already includes the encoder counts per revolution, polarity, gearing and wheel radius. A calibration push compares that raw travel with a distance you measure yourself (tape measure or field tiles), which gives one number per wheel: `travel_scale`.

That number lumps together:
- radius error;
- gearing error;
- tire compression;
- slip.

A single push cannot tell them apart. A constant scale does not fix slip, missed encoder counts, compression that changes with load, or magnet eccentricity that varies with shaft angle.

Before calibrating:
- Get the radius, counts per revolution, gearing and polarity physically right first.
- Never use the travel scale to hide a wrong one. Corrections beyond 10 percent are refused for that reason.
- Never calibrate against naviGATR's own pose.

**Procedure (forward wheel, then sideways wheel)**
1. Open the Wheel calibration page. LEFT/RIGHT selects the wheel (port 1 forward, port 0 sideways).
2. Set the reference distance you will push: L1/R1 change it by 1 cm, L2/R2 by 10 cm. The starting value is `kCalibrationDistance` (1.0 m). Use at least 0.5 m.
3. Put the robot against a straight edge with room to push along the wheel's measuring direction (forward for port 1, left for port 0).
4. Press UP. The program reads the wheels.
5. Push the robot exactly the reference distance, straight, without turning it. Measure the distance at a point near the robot origin (the point the profile positions are measured from): the program removes the wheel's own share of any small rotation, but not the tape point's.
6. Press DOWN. The trial is accepted or rejected with a reason:
   - reading stale;
   - encoder restarted;
   - robot rotated (more than 0.5 degree);
   - push not along the wheel (the cross wheel moved more than 5 percent);
   - wrong direction or polarity;
   - wheel barely moved;
   - scale out of range: check the radius, CPR and gearing;
   - profile changed.
7. Repeat until at least 3 trials agree within 1 percent. The page then shows READY and the proposed scale.
8. Press A to apply it now:
   - the Brain sends a new profile, and the Pi rebuilds its models with a new baseline, so the change cannot look like motion;
   - this ends the current placement;
   - A again places the robot at the pose it had before the change.
9. Make it permanent: copy the shown value into that wheel's `w.travel_scale` in `gatr2_robot.h`, then rebuild and upload.

The perpendicular wheels calibrate independently: a forward push must leave the sideways wheel still, and the reverse.

**Periodic (angle dependent) correction is not implemented.** The Pico counts quadrature edges from an arbitrary zero at power-up. A repeatable per-angle table would need an index pulse, absolute angle, or homing, which the current encoders and firmware do not provide.

## 5. IMU calibration and reinitialization

**VEX IMU (bench source)**
- The VEX firmware owns its calibration. The Pi applies no bias of its own, so the calibration is never applied twice.
- X on the Status page first asks the Pi to check that the wheels stayed still over the last 300 ms. Only then does the Brain start the VEX calibration (`pros::Imu::reset()`); "robot moving" starts nothing. Hold still for about 2 s: the check covers the start, not the calibration itself. The IMU samples are invalid meanwhile, so the pose becomes invalid (section 8): place the robot again afterwards.
- The VEX IMU gives heading only, so stationary detection on the Pi uses the wheels and the heading change. There is no raw gyro rate or acceleration.

**Pico IMU (BNO08X or ASM330)**

| Step | What it does |
|---|---|
| Gravity alignment | On the BNO08X, at every IMU start. It finds the up axis over 2 s still and level, which makes yaw correct for any fixed mounting. It does not track later rocking or tilt, and gives neither field heading nor mounting yaw. |
| Gyro bias | Measured by the Pi over a still window: wheels still, gyro steady, samples fresh and continuous. Movement restarts the window. Without a still window in 60 s the calibration fails and X retries. The bias is re-measured after any Pico or IMU restart. If the robot is placed and moves before the bias is measured (a recalibration, or a placement during the first calibration), that motion is lost and the pose becomes invalid ("motion lost"): keep the robot still until readiness shows Ready. |
| Bias upkeep | While the robot stays still after calibration, the bias is nudged by bounded steps. Any movement or doubtful data stops it at once. |
| Field heading | Comes only from placement. |

- X starts a recalibration; the Pi refuses it while the robot moves.
- Y asks the Pico to reinitialize its IMU, then recalibrates. The IMU restarts, so with a Pico IMU profile the pose becomes invalid (section 8): place again afterwards.

**Stationary handling.** While a still window qualifies, the Pi reports zero velocity and the "stationary" flag. This is gated stationary handling, not a ZUPT filter:
- none of the estimators here models velocity with uncertainty;
- it does not undo drift from before the stop.

**Reinitialize localization** (L1+R1+A) starts a new odometry epoch and needs a new placement. Use it after moving the robot with the Pi off, or when the pose is known to be wrong.

## 6. Placement

- **Program start:** the robot is placed at `kStartPose` once, after the link, profile and sensors are ready and the Pi IMU calibration has settled, within `kStartupWaitSeconds` of program start. A failed IMU calibration holds it until X recalibrates. `kStartupPolicy` chooses:
  - `kAlways` (default): place at program start.
  - `kIfUnplaced`: keep a placement the Pi still holds, for example after a Brain restart mid-match.
  - `kNever`: you place explicitly.
- **Explicit placement:** A (locaGATR) or UP (testing) places at the start pose. Put the robot there first.
- **The Brain never re-places the robot on its own** after:
  - a reconnect;
  - a Pi restart;
  - a profile change;
  - a reinitialization.

  The screen shows "Needs placement" instead.

## 7. Drive test program

`operaGATR` drives the robot with actuGATR.

**Controls**
- Left stick Y drives forward and right stick X turns; left stick X strafes on mecanum.
- A runs the direct test, X the avoiding test, Y the landmark test.
- B cancels. Moving a stick also takes over from a running test.
- UP places at the start pose.
- DOWN recalibrates the IMU, only while no movement runs and after the Pi's stillness check (as X in locaGATR). While it calibrates, the tests are refused and the sticks do nothing.
- LEFT/RIGHT changes the speed scale.

**Tests**

| Button | Test |
|---|---|
| A | `goToDirect(kDirectGoal)`: from the current pose to the fixed (72 inches, 24 inches, 90 degrees) destination, relative to the field origin; no obstacle checks |
| X | `goToAvoiding(kAvoidGoal)`: same destination as A, routing around the field's obstacle boxes |
| Y | `goToAvoiding(kLandmarkOffset, landmark())`: relative to a named landmark from the generated `Field` table. Without a camera it uses the landmark's nominal map pose (`kRequireObservedLandmark = false`). |

- autonomous() runs the direct test, then the avoiding test.
- disabled() stops the drive.
- The screen shows the command state and reason, errors, cross-track, segment and plan count, which is what you tune by.
- The last row shows the VEX IMU tilt and whether telemetry is on, off or refused by the Pi. The same movement status, commanded speeds and wheel targets go to the Pi viewer as telemetry every 100 ms (section 10).

The current test starts at (7 inches, 24 inches, heading 0 degrees). A does not re-place the robot:
manual movement before pressing A is included in the localized starting pose.
Tank mode turns toward the destination, drives the straight segment and turns
to the final heading. Mecanum mode translates while changing heading; it is
currently selected in operaGATR, with four independent corner motor groups.
Its approximate geometry and motor assignments are configured; motor/encoder
directions and follower gains still need checking on the robot.
The start pose and wheel geometry live in
`brain/robot/gatr2_robot.h`; the destination and drivetrain settings live in
`brain/operaGATR/include/robot_config.h`. Rebuild and upload the Brain after
changing these; the Pi's `brain_profile_usb.xml` receives the robot profile.

**Tuning:** see [actuGATR tuning](actugatr.md#tuning). Start at speed scale 0.3.

**Planner limit:**
- The planner treats the robot as a circle around its origin: the footprint's farthest corner plus the clearance.
- On the Override field that circle cannot pass between diagonal goals for robots larger than about 0.4 m square. An 18 inch robot is refused there and must use direct moves in those areas.
- The same closes each corner pocket between the walls and its two nearest goals, around (0.6, 0.6) and the other corners. An avoiding move from inside one fails with "no path"; drive out with a direct move first.
- The current start is close to the red wall. A ignores field bounds and obstacles; X/Y check the footprint and configured clearance. The host end-to-end tests use their own field-valid starting poses.
- For the current (7 in, 24 in) to (72 in, 24 in) test, A crosses `red_goal_3_south` near (46.66 in, 23.11 in). Use X on the assembled field. The initial rear wall gap is approximately 9 mm; the avoiding planner supports a straight exit from this near-wall pose before normal routing.
- See [investiGATR](investigatr.md).

## 8. Sensor loss and recovery

**Rule:** if a sensor the active profile uses for localization stops delivering, the pose is invalid until you place the robot again. Both programs show "POSE INVALID: put the robot at the start pose" and the readiness line says "Needs placement". Sensors the profile does not use never matter.

| Used sensor | Lost when |
|---|---|
| Tracking wheel encoders | no Pico frames for more than 250 ms (Pico link or power), a Pico reboot or counter restart, or a used encoder channel missing from its frames |
| Brain VEX IMU | no valid sample at the Pi for more than 250 ms. The samples ride on the Brain link, so this includes a USB drop, a Brain program restart and a VEX recalibration. |
| Pico IMU (only when the profile uses it) | stale for more than 250 ms, failed, or reinitialized |

A quadrature encoder whose cable is pulled keeps its last count, which looks the same as standing still; that case cannot be detected. A dead Pico IMU with a VEX IMU profile changes nothing: the Pico keeps retrying it (5 quick attempts, then every 30 s) while the encoders keep flowing.

**Recovery by event**

| Event | What happens |
|---|---|
| USB cable out and back in | The Brain keeps its session and resumes when replies return. Over 250 ms with a VEX IMU profile: pose invalid. A movement that was running has failed and does not resume. |
| Brain program restart | The Brain opens a new session; the Pi still runs the same profile, so nothing is uploaded. With a VEX IMU profile the pose is invalid (IMU samples stopped); startup placement (`kAlways`) places at the start pose again. Old movements are gone. |
| Pi restart | The Brain sees a new Pi instance, uploads the profile again, and reads the field map again. The Pi starts unplaced. |
| Pico restart | The Pi sees the new boot identity: pose invalid. |
| IMU recalibration (X, DOWN) or Pico IMU reinit (Y) | Pose invalid afterwards: place again. |
| Interrupted profile or map transfer | Resumed or restarted. Partial documents are never used. |
| Serial device missing at Pi start | Retried once a second. |

**What needs you:**
- a placement after any sensor loss, a Pi restart, a profile change, a recalibration or a reinitialization: put the robot at the start pose and press A (locaGATR) or UP (testing);
- IMU recalibration after moving the robot during calibration;
- wheel calibration values made permanent in `gatr2_robot.h`;
- fixing a rejected profile;
- restarting a movement.

## 9. Tests run and what is not validated

The host test suites cover:
- the wire protocol;
- the Brain link client;
- the planner;
- motion and drives in simulation;
- the Pi pipeline over memory links;
- the Pico logic.

The final report lists the exact counts. Not validated until tried on the robot:
- the USB and RS-485 links on real hardware;
- the Pi to Pico command wire on the HAT;
- the tracking wheel geometry and radius;
- IMU behavior;
- motor directions and gains;
- the collision boxes against a real field;
- planning times on the V5;
- the VEX IMU roll and pitch conventions and the mount yaw (section 10);
- the cost of telemetry on the V5 link timing.

## 10. Telemetry and attitude

Both programs send TELEMETRY to the Pi every 100 ms for the browser viewer and
its recordings:

- locaGATR: the robot tilt (roll and pitch) from the VEX IMU, when the profile uses it.
- operaGATR: the tilt, plus the movement command's state, reason, destination, commanded speeds, errors and drive fault, and the motor velocity targets.

The Pi only shows and records it. Localization, placement and the profile
never use it, and a missing or refused telemetry changes nothing else. Only
tilt is sent: no height or vertical position.

**Settings** (`brain/robot/gatr2_robot.h`, then rebuild and upload the Brain
programs; nothing on the Pi or the Pico changes):

| Setting | Default | Meaning |
|---|---|---|
| `kSendTelemetry` | true | false sends nothing |
| `kTelemetryPeriodMs` | 100 | period of both programs and the link's limit |
| `kVexImuMountYawDeg` | 0, PLACEHOLDER | direction the VEX IMU's +x axis points in the robot frame, CCW from forward: 0 forward, 90 left, 180 backward, 270 right. The IMU must lie flat. It affects only the tilt shown, never the heading |

**Pi version.** Showing it needs the Pi software with TELEMETRY support. An
older Pi answers "unsupported"; the Brain then stops sending for that session
and keeps working. The screens show it: operaGATR "Telemetry refused by the
Pi", locaGATR "(no TM)" after the tilt.

**Cost.** Each telemetry exchange uses the one request slot of the link and
can push the next state poll back by about 10 to 15 ms (one exchange plus the
5 ms gap), more on a slow link. In host simulations at 100 ms, state polls
fell by 6 to 11 percent at the default timing and by up to 20 percent on
slow links (see [communiGATR telemetry](communigatr.md#telemetry)). It was
not measured on the robot. If pose updates to the Brain matter more, set
`kSendTelemetry = false` or a longer period.

**Slow link.** When a state request and its reply take about 15 ms or more,
the poll is due at every turn. That is plausible on the V5 USB console (its
transmit task idles 2 ms and its receive task waits 5 ms after an empty
read, and the Pi answers once per 10 ms loop) but not measured.
Telemetry then goes half a period late, taking one poll's turn at most every
150 ms: about 6 reports a second instead of 10, each wait under 250 ms
in the host runs. The Pi still shows the tilt as measured; it shows it as
stale if no report arrives for 250 ms. `ClientStats::telemetry_overdue`
(`ProsLinkStatus::stats`) counts these late sends.

**Sign conventions.** Robot frame +x forward, +y left, +z up. Roll is about
+x: positive when the left side is up. Pitch is about +y: positive when the
nose is down. The Brain assumes the VEX IMU reports roll and pitch with the
same convention in its own frame and turns them into the robot frame with the
mount yaw, exactly (not a small angle approximation). The VEX convention is
UNVERIFIED: check it once on the bench.

**Bench check** (not yet done on hardware):

1. Set `kVexImuMountYawDeg` to your best guess, build and upload locaGATR.
2. Start it with the robot level and still. Wait until the VEX IMU shows `ok`
   on the Status page; the row then reads `VEX P1 ok <heading> deg r <roll> p <pitch>`.
3. Level: `r` and `p` should be near 0. A degree or two is the mounting and the
   floor, not a sign error.
4. Lift the front about 10 to 15 degrees (a block under the front): expect `p`
   **negative** (nose up) and `r` near 0.
5. Lift the left side instead: expect `r` **positive** and `p` near 0.
6. The viewer should show the model tilted the same way, marked as measured.

| You see | Fix |
|---|---|
| lifting the front moves `r`, lifting the left moves `p` | the mount yaw is off by 90: try 90 or 270 |
| both signs wrong | the mount yaw is off by 180 |
| one sign wrong at every mount value | the VEX convention differs from the assumed one: note what you saw and report it; the fix is a sign in `brain/communiGATR/src/attitude.cpp` and its tests |

After a change, upload again and repeat steps 3 to 5.

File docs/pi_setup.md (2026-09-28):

# Raspberry Pi setup and automatic startup

This setup runs naviGATR with a Brain-profiled configuration whenever the Pi
boots. Internet is needed to install build packages once. Afterwards
localization and the 3D viewer work offline; Ethernet is only needed to view or
manage the Pi. Power the Pi separately from the Ethernet cable.

The robot is described on the Brain, in
[brain/robot/gatr2_robot.h](../brain/robot/gatr2_robot.h), and sent to the Pi as
a robot profile each time the Brain connects; the Pi config names only its own
devices. The current bench: Pico encoder ports 0 (forward) and 1 (sideways),
the VEX IMU on Brain Smart Port **1**, and the Brain-Pi link over **USB**. The
Pi needs the config that matches the Brain's link:

| Brain link (`kUseUsb` in `gatr2_robot.h`) | Pi config |
|---|---|
| USB (`true`, the bench) | `config/override/brain_profile_usb.xml` |
| RS-485 on a Smart Port (`false`, `kLinkPort`) | `config/override/brain_profile_rs485.xml` |

That is the only Brain setting the Pi must match; nothing detects the
transport automatically. Build and upload the
[Brain locaGATR app](brain_setup.md#2-build-and-upload); the Pi service
does not start a program on the Brain. See
[Brain robot profiles](../pi/naviGATR/docs/brain_profile.md) for what the Pi does
with the profile and [USB bench](../pi/naviGATR/docs/usb_localization_bench.md)
for the bench procedure.

## 1. Get the Pi online once, over Ethernet

If you already enabled the direct `robot-direct` profile, first use the
[return-to-router steps](#6-return-to-router-ethernet-when-you-need-internet).

Use Raspberry Pi OS with NetworkManager (Bookworm or later). For a fresh SD card,
set a username, password, hostname, and **enable SSH** in Raspberry Pi Imager.
Wi-Fi configuration is unnecessary. On an existing installation, enable SSH from
its local terminal:

```sh
sudo systemctl enable --now ssh
```

Connect the Pi and Windows computer to an internet-connected router by Ethernet.
Leave Windows Ethernet IP and DNS on **Automatic (DHCP)** for this step. Find the
Pi's address in the router's client list, or run `hostname -I` on the Pi. From
Windows PowerShell, replacing the example username and address:

```powershell
ssh YOUR_USER@PI_ROUTER_IP
```

The configured hostname, such as `gatr2.local`, may also work. These are ordinary
[Raspberry Pi SSH connections](https://www.raspberrypi.com/documentation/computers/remote-access.html).
All shell commands below run on the Pi unless labeled Windows.

Install the tools needed for this camera-free build:

```sh
sudo apt update
sudo apt install -y build-essential cmake git
```

## 2. Transfer the current code and build

**Use the current working files for this bench test.** `git pull` cannot retrieve
changes that have not been committed and pushed. To copy the current Pi program
and shared protocol from Windows, run these in the repository's top directory:

```powershell
tar.exe -czf "$env:TEMP\navigatr-source.tar.gz" --exclude=build --exclude=build-* --exclude=.pio pi/naviGATR translaGATR
scp "$env:TEMP\navigatr-source.tar.gz" YOUR_USER@PI_ROUTER_IP:/tmp/navigatr-source.tar.gz
```

Then on the Pi:

```sh
mkdir -p ~/GATR2-Electronics
tar -xzf /tmp/navigatr-source.tar.gz -C ~/GATR2-Electronics
cd ~/GATR2-Electronics/pi/naviGATR
cmake -S . -B build-bench -DCMAKE_BUILD_TYPE=Release \
  -DNAVIGATR_BUILD_TESTS=OFF -DNAVIGATR_WITH_LIBCAMERA=OFF
cmake --build build-bench -j2
```

This replaces files with the same names, so preserve Pi-only calibration edits
before repeating the transfer. Once the changes are published, a normal clone of
`https://github.com/Edison-LaraBojay/GATR2-Electronics.git` also works. The viewer
is built into the executable and requires no browser internet/CDN.

## 3. Enable the HAT serial connections

Run `sudo raspi-config`, select its serial-port interface settings, disable the
**serial login shell**, and enable the **serial port hardware**. The Pico link
and Brain link must not be used by a serial console.

The HAT's Brain interface uses UART5 on GPIO12/13. Ensure
`/boot/firmware/config.txt` includes these lines in an applicable section:

```text
enable_uart=1
dtoverlay=uart5
```

Reboot with `sudo reboot`, reconnect by SSH, and inspect the UART devices:

```sh
ls -l /dev/serial* /dev/ttyAMA*
```

Both Brain-profile configs use `/dev/ttyAMA0` for the Pico at 115200 baud;
`brain_profile_rs485.xml` also uses `/dev/ttyAMA5` for the Brain (UART5 is only
needed for RS-485; USB finds the Brain's USB port itself). Confirm these paths
on the Pi. On Pi 4, the primary header UART can be
`/dev/ttyS0` rather than `/dev/ttyAMA0` depending on Bluetooth/UART overlays;
`/dev/serial0` identifies the primary UART when that alias is available. Update
the XML to match the hardware instead of assuming the suffixes. The official
[UART documentation](https://www.raspberrypi.com/documentation/computers/configuration.html#configuring-uarts)
describes the primary UART aliases and overlays.

The RS-485 Brain link also uses a driver-enable pin. Its XML `gpio` value is a
**sysfs GPIO number**, which may differ from the BCM number: on a kernel whose
GPIO chip starts at 512, BCM GPIO6 is **518**, not 6. Check
`/sys/class/gpio/gpiochip*/base` and the chip labels. See
[serial resource configuration](navigatr_resources.md#linux_serial_link) and the
[RS-485 bench test](../bench/rs485_link/README.md). Software device names and GPIO
numbering must match this Pi's configuration.

## 4. Enable automatic startup

Stop any manually running naviGATR first (Ctrl+C in its terminal). The installer
does not stop unrelated processes. From the Pi's program directory, install the
service as your normal Pi account:

```sh
cd ~/GATR2-Electronics/pi/naviGATR
sudo bash tools/install_service.sh --user "$USER"
sudo systemctl status navigatr --no-pager
sudo journalctl -u navigatr -n 50 --no-pager
```

The installer defaults to `build-bench/navigatr` and
`config/override/brain_profile_usb.xml`. It enables and starts
`navigatr.service`, which runs without an SSH session or network connection and
restarts after a process exit. Logs go to the journal. It uses absolute paths to
this checkout; rerun the installer if you move it.

The same with the config named explicitly, and the RS-485 variant:

```sh
sudo bash tools/install_service.sh --user "$USER" --config config/override/brain_profile_usb.xml
sudo bash tools/install_service.sh --user "$USER" --binary build-bench/navigatr \
  --config config/override/brain_profile_rs485.xml
```

Changing the robot's geometry, encoders, IMU source or footprint is a Brain
upload; the service keeps running and applies the new profile when the Brain
connects. Changing between USB and RS-485, or editing the Pi XML, needs the
installer (or `sudo systemctl restart navigatr` after an XML edit).

Add `--dry-run` to inspect the unit without installing it. The unit grants the
existing Raspberry Pi OS `dialout` and `gpio` groups to the service; installation
reports an error if either required group is missing. A green
service status alone does **not** prove either link is working: check the journal
for UART/GPIO permission or device faults, then confirm changing encoder/IMU
readings and pose in the Brain app and viewer. The Pico UART (and the RS-485
UART) are `required`: startup fails and the service retries if they are
unavailable. The Brain USB port is optional and retried once per second.

The journal shows the lifecycle as `event: ...` lines: the Brain session,
`profile <id> applied (...)` or `refused: <reason>`, calibration results, Pico
restarts, and `sensor lost: ...: place again` or `motion lost: ...: place
again` (a model had to discard motion it measured).

Useful commands:

```sh
sudo systemctl restart navigatr             # reload changed XML / rebuilt binary
sudo journalctl -u navigatr -f              # live logs; Ctrl+C leaves it running
sudo systemctl stop navigatr                # stop until reboot or manual start
sudo systemctl disable --now navigatr       # stop and disable automatic startup
sudo systemctl enable --now navigatr        # enable again
```

Stop the service before running the executable manually so two processes do not
compete for the UARTs or viewer port. For source updates: stop, transfer/rebuild,
then start it again. Reboot once to confirm startup and the viewer return without
manually launching naviGATR.

The Brain app places the robot at its start pose once, when the link, profile
and sensors are ready. If it gave up waiting (the Pi booted too slowly), or the
pose was lost later, put the robot at the start pose and press controller
**A**. That places it without restarting the Pi service.

## 5. Set up direct Windows-to-Pi Ethernet

Do this after online installation. Use a subnet that does not overlap another
active connection; these examples use `192.168.50.0/24`.

First create the saved direct profile on the Pi **without activating it yet**:

```sh
nmcli device status
nmcli connection show
sudo nmcli connection add type ethernet ifname eth0 con-name robot-direct \
  ipv4.method manual ipv4.addresses 192.168.50.2/24 \
  ipv4.never-default yes ipv6.method disabled \
  connection.autoconnect no connection.autoconnect-priority 100
```

Replace `eth0` if the Ethernet interface has a different name. If `robot-direct`
already exists, use `nmcli connection modify robot-direct` with the settings
instead of adding a duplicate. Keep the original DHCP/router profile and record
its name for switching back. NetworkManager chooses higher
[autoconnect priorities](https://www.networkmanager.dev/docs/api/latest/settings-connection.html)
when bringing up a connection; it cannot infer whether the cable goes to your
computer or router.

When ready to switch, run on the Pi:

```sh
sudo nmcli connection modify robot-direct connection.autoconnect yes
sudo nmcli connection up robot-direct
```

**The current router SSH connection will drop.** Move the cable so the Pi connects
directly to the computer. In Windows, open **Settings > Network & internet >
Ethernet > IP assignment > Edit**, choose **Manual**, enable IPv4, and set:

| Setting | Windows | Pi (already saved) |
|---|---|---|
| Address | `192.168.50.1` | `192.168.50.2` |
| Subnet mask / prefix | `255.255.255.0` / `24` | `/24` |
| Gateway and DNS | Leave blank | None |

Windows saying "No internet" is expected. This direct connection does not share
the computer's internet access. From Windows:

```powershell
ssh -L 8765:127.0.0.1:8765 YOUR_USER@192.168.50.2
```

Open **http://127.0.0.1:8765/** on Windows. Keep this SSH window open while viewing.
To forward the viewer without an interactive terminal, add `-N`. Closing the
viewer or disconnecting Ethernet does not stop the Pi service. The
[inspection guide](../pi/naviGATR/docs/inspection.md) explains the field, pose,
Brain link readiness and diagnostics. The Brain-profile configs have no live
camera or AprilTag updates.

## 6. Return to router Ethernet when you need internet

Before unplugging the direct cable, run on the Pi:

```sh
sudo nmcli connection modify robot-direct connection.autoconnect no
sudo reboot
```

During reboot, connect the Pi to the router. Restore Windows Ethernet IP and DNS
to **Automatic (DHCP)** if connecting the computer to the router too. The Pi's
retained DHCP profile can then autoconnect; find its router address and SSH there.
If that original profile has autoconnect disabled, enable it by its recorded name
before rebooting. A local keyboard/display can also run
`nmcli connection up "YOUR_DHCP_PROFILE"` to recover access.

To return to the direct cable, repeat the two activation commands in step 5 and
restore Windows's static address. Automatic naviGATR startup is independent of
the Ethernet profile. Before disconnecting Pi power, shut down with
`sudo poweroff` when practical.

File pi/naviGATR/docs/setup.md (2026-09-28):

# Set up and run Navigatr

Start here to bring up a Raspberry Pi 4, Pico, IMU, tracking wheels, and camera,
then see robot localization and landmark estimates in the browser.

**The primary path is a Brain-profiled config**: the robot is described in
Brain C++ and sent to the Pi as a robot profile, so the Pi XML holds no robot
geometry. That path is the next section. The rest of this guide covers the
XML-configured profiles (**three tracking wheels + IMU + camera**, and the
**two parallel tracking wheels + BNO08X** [bring-up guide](parallel_wheel_bringup.md)),
which still run and are needed for a camera. Their XML files are templates:
actual wheel measurements, camera calibration, mounting, and starting position
must be supplied.

## Brain-profiled robot (primary)

This runs the current bench setup (forward wheel on encoder port 0, sideways
wheel on port 1, Brain VEX IMU, USB) and every other supported setup the Brain
selects: two wheels or two forward wheels with the Pico IMU or the VEX IMU, and
three wheels with or without the Pico IMU. No camera or AprilTags are needed.

1. Prepare the Pi and Pico as in [Prepare the Pi and Pico](#prepare-the-pi-and-pico).
   The Pico UART is `/dev/ttyAMA0`; RS-485 also needs UART5 and the DE GPIO.
2. Build without the camera backend and install the service with the config
   that matches the Brain's link (see [Pi setup](../../../docs/pi_setup.md)):

   ```sh
   cmake -S . -B build-bench -DCMAKE_BUILD_TYPE=Release -DNAVIGATR_BUILD_TESTS=OFF -DNAVIGATR_WITH_LIBCAMERA=OFF
   cmake --build build-bench -j2
   sudo bash tools/install_service.sh --user "$USER" --config config/override/brain_profile_usb.xml
   ```

   For RS-485 use `config/override/brain_profile_rs485.xml` instead. The two
   differ only in the Brain link; this is the one setting the Brain cannot
   change for the Pi.
3. Before a Brain connects the Pi waits: the log and the viewer show no pose,
   profile none, and the raw encoder counts in the sources table.
4. Start the Brain program (`brain/locaGATR` or `brain/operaGATR`, see
   [Brain setup](../../../docs/brain_setup.md)). It sends the profile; the Pi
   logs `event: profile <id> applied (...)` with the wheels, IMU and footprint,
   or the refusal reason. Hold the robot still while the IMU starts.
5. The Brain places the robot at its start pose. The viewer's Brain link panel
   then reads `ready`.

Edit robot geometry, encoder settings, the IMU source and the footprint in
[brain/robot/gatr2_robot.h](../../../brain/robot/gatr2_robot.h), then rebuild
and upload the Brain program; no Pi change or restart. Details, refusals,
calibration and recovery: [Brain robot profiles](brain_profile.md).

## Choose your configuration

| Hardware | Main configuration template | Robot measurement template | Pipeline template |
|---|---|---|---|
| Any supported setup, robot described on the Brain | [brain_profile_usb.xml](../config/override/brain_profile_usb.xml) or [brain_profile_rs485.xml](../config/override/brain_profile_rs485.xml) | none: the Brain sends it | inside the main file |
| Three wheels + IMU + camera | [three_wheel_imu_camera.xml.in](../config/override/diagnostics/three_wheel_imu_camera.xml.in) | [gatr2_as5047_imu.xml.in](../config/shared/robots/gatr2_as5047_imu.xml.in) | [three_wheel_imu_camera_pipeline.xml.in](../config/override/diagnostics/three_wheel_imu_camera_pipeline.xml.in) |
| Two parallel wheels + BNO08X, no camera | [parallel_wheels_bno08x.xml](../config/override/diagnostics/parallel_wheels_bno08x.xml) | [gatr2_parallel_wheels_bno08x.xml.in](../config/shared/robots/gatr2_parallel_wheels_bno08x.xml.in) | [parallel_wheels_bno08x_no_camera.xml](../config/shared/pipelines/parallel_wheels_bno08x_no_camera.xml) |
| Two parallel wheels + BNO08X + camera | [parallel_wheels_bno08x_camera.xml](../config/override/diagnostics/parallel_wheels_bno08x_camera.xml) | same | [parallel_wheels_bno08x_camera.xml](../config/shared/pipelines/parallel_wheels_bno08x_camera.xml) |

The camera profiles use [gatr2_front_camera.xml.in](../config/shared/robots/gatr2_front_camera.xml.in),
and all use the nominal [Override field definition](../config/override/field.xml).
The three-wheel template uses encoders **A + B + C**. The parallel-wheel
profiles use encoder channels 0 and 1 only, share one localization fragment,
get their starting field pose from the Brain, and need no third wheel; follow
the [parallel-wheel guide](parallel_wheel_bringup.md) for them.

For an XML-configured profile, follow these sections in order:

1. [Prepare the Pi and Pico](#prepare-the-pi-and-pico).
2. [Build and check the viewer](#build-and-check-the-viewer).
3. [Create your robot configuration](#create-your-robot-configuration).
4. [Measure the wheels and IMU sign](#measure-the-wheels-and-imu-sign).
5. [Bring up and calibrate the camera](#bring-up-and-calibrate-the-camera).
6. [Configure camera mounting and field placement](#configure-camera-mounting-and-field-placement).
7. [Run and check the robot](#run-and-check-the-robot).
8. [Connect the Brain](#connect-the-brain).
9. [Find the outputs](#find-the-outputs).

## Prepare the Pi and Pico

Install Raspberry Pi OS with SSH enabled and configure the account, hostname,
and network. The camera backend targets the libcamera stack used by Bookworm
and newer Raspberry Pi OS releases. Connect from your computer:

```sh
ssh <user>@<pi-host>
```

On the Pi, install the build and camera tools and obtain this repository:

```sh
sudo apt update
sudo apt install git build-essential cmake pkg-config libcamera-dev rpicam-apps libgtest-dev
git clone <repository-clone-url> GATR2-Electronics
cd GATR2-Electronics/pi/naviGATR
```

An existing `rpicam-apps-lite` installation is also sufficient for headless
camera checks. Unless a block says otherwise, subsequent Pi commands run from
`GATR2-Electronics/pi/naviGATR`. Reuse an existing checkout instead of cloning
over it. See [Pi access](../../../docs/pi_setup.md) for SSH troubleshooting.

### Pico firmware and wiring

Install [PlatformIO for VS Code](https://docs.platformio.org/en/stable/integration/ide/vscode.html)
on the development computer, open this repository's `pico` project, and run from
its PlatformIO terminal:

```sh
cd pico/aggreGATR
pio run -e hat2_bno08x
pio run -e hat2_bno08x --target upload
```

Use the board revision's schematic and [Pico pin map](../../../pico/aggreGATR/src/board.h)
for connections. The firmware reads the encoder A/B quadrature channels and the
IMU through the Pico: `hat2_bno08x` for the BNO08X, `hat2_asm330` for the
ASM330. It sends binary telemetry to the Pi at 115200 baud. [Pico firmware](../../../pico/README.md) and
[hardware interfaces](../../../docs/hardware.md) describe the pin map and protocol;
the [Pico link](pico_link.md) describes its identity, status and commands.
Update the Pi software before flashing new Pico firmware: the new firmware
sends sensor frames that older Pi builds drop.

The BNO08X learns a fixed up axis during a stationary, level startup and
projects gyro XYZ onto it, supporting sideways or upside-down IMU mounting.
ASM330 firmware still reads physical gyro Z. Both send yaw rate without live
roll/pitch; the camera profiles use the documented level assumption until an
attitude source is added. Startup alignment does not compensate dynamic rocking.
Camera mounting pitch/roll are still configured and applied.

### Pi UART configuration

Use `sudo raspi-config` to disable the serial login console and enable serial
hardware. For the HAT's Brain UART, add the following to
`/boot/firmware/config.txt` and reboot:

```ini
enable_uart=1
dtoverlay=uart5
```

Check the resulting device names:

```sh
ls -l /dev/serial* /dev/ttyAMA*
```

The robot templates select `/dev/ttyAMA0` for the Pico and `/dev/ttyAMA5` for the
Brain. Confirm these against the actual GPIO routing and OS device mapping and
edit each resource's `<Device path="..."/>`. `/dev/serial0` identifies the
primary UART and may resolve to a different device. On a Pi 4, assigning PL011
UART0 to the primary pins can require a Bluetooth/UART overlay choice; follow
the [Raspberry Pi UART documentation](https://www.raspberrypi.com/documentation/computers/configuration.html#configuring-uarts)
for the wiring you actually use.

If the serial devices belong to `dialout`, grant the runtime account access and
log out and back in:

```sh
sudo usermod -aG dialout "$USER"
```

The Brain link also uses GPIO6 as the RS-485 DriverEnable, through sysfs
(`/sys/class/gpio`). That needs GPIO access for the runtime account; serial
group membership alone does not provide it, and the configured number may need
the kernel's sysfs offset (see [Connect the Brain](#connect-the-brain)). For
initial viewer-only bring-up, select `<CommandCollection type="noop"/>` and
`<Publishing type="noop"/>` together in your completed pipeline file (the
brain link slots are a pair) and remove the `brain_uart` resource from your
completed robot file. This avoids opening or driving a Brain link you are not
testing.

## Build and check the viewer

Build on the Pi with the camera backend enabled:

```sh
cmake -S . -B build -DCMAKE_BUILD_TYPE=Release -DNAVIGATR_WITH_LIBCAMERA=ON
cmake --build build -j4
ctest --test-dir build --output-on-failure
```

If the Pi runs out of memory while compiling, use `-j2` or `-j1`. Ordinary
desktop builds can run simulation but do not provide Pi camera capture;
Windows build commands are in the [README](../README.md#build).

First verify the software without hardware:

```sh
./build/navigatr --config_file="config/demo/synthetic_field_demo.xml"
```

On your computer, open a second terminal for the SSH tunnel:

```sh
ssh -N -L 8765:127.0.0.1:8765 <user>@<pi-host>
```

Open `http://127.0.0.1:8765/` in your computer's browser. You should see the 3D
field, moving robot and trail, nominal and estimated goals, and a synthetic
camera image with real detector output. The browser performs the 3D rendering;
the Pi needs no desktop. Keep the tunnel running. Ctrl-C stops Navigatr cleanly.

## Create your robot configuration

Copy only the set you need. These commands preserve an existing destination;
edit the completed `.xml` files, keeping the `.xml.in` templates for reference.

For **three wheels + IMU + camera**:

```sh
cp -n config/shared/robots/gatr2_as5047_imu.xml.in config/shared/robots/gatr2_as5047_imu.xml
cp -n config/shared/robots/gatr2_front_camera.xml.in config/shared/robots/gatr2_front_camera.xml
cp -n config/override/diagnostics/three_wheel_imu_camera_pipeline.xml.in config/override/diagnostics/three_wheel_imu_camera_pipeline.xml
cp -n config/override/diagnostics/three_wheel_imu_camera.xml.in config/override/diagnostics/three_wheel_imu_camera.xml
```

For **two parallel wheels + BNO08X**, see the
[parallel-wheel guide](parallel_wheel_bringup.md#3-fill-in-the-robot-description).
That template needs only wheel geometry and wheel-direction tokens filled in.
It uses 4000 counts/revolution for default AS5047P settings with direct 1:1
coupling, and IMU `invert="false"` for the Pico's aligned yaw. Check the encoder
count when testing; change it if its settings or gearing differ.

Replace every `@...@` parameter in the selected files. A `.xml.in` file or an
unresolved parameter is not runnable. `calibration_status` is only a note for
the reader; setting it to `verified` does not validate or enable anything.

| File | Information you put there |
|---|---|
| Main `*_imu_camera.xml` | Referenced files, loop/inspection rates, visible robot-body dimensions. |
| Robot `gatr2_*as5047_imu.xml` | Serial ports, encoder CPR/sign, gyro sign, wheel radius/position/direction. |
| Camera `gatr2_front_camera.xml` | Camera selection, capture mode, lens intrinsics, camera mounting, tag corner size. |
| Local `*_imu_camera_pipeline.xml` | Selected wheels, gyro bias settings, estimator, initial field pose, history, association gates, brain link slots. |
| `config/override/field.xml` | Nominal field and landmark/tag-mount geometry. Competition displacements are estimated at runtime. |

The main document references the robot and camera fragments separately. Paths
are relative to the XML containing them. Keep this directory layout or update
the references when moving a file. Inline sections and `file="..."` references
are supported as described in [configuration](configuration.md).

## Measure the wheels and IMU sign

Choose one fixed robot origin near the nominal turning center. Use this same
point for wheel geometry, camera mounting, initial field placement, and the
reported robot position. Robot axes are **+x forward, +y left, +z up**; heading
is positive counterclockwise viewed from above.

| XML value | How to determine it |
|---|---|
| Sensor `counts_per_revolution` | Counts emitted by the Pico for one shaft revolution, including its quadrature decoding. Confirm by several full turns; do not substitute an encoder datasheet number without checking the configured output. |
| Sensor `invert` | Electrical sign normalization. Rotate in the defined positive shaft direction and check the reported direction. |
| Wheel `radius_m` | Effective rolling radius under robot load. Measure travel over several turns; radius = travel / (2 pi x revolutions). |
| Wheel `position_x_m`, `position_y_m` | Wheel contact-point coordinates relative to the robot origin. |
| Wheel `measurement_angle_deg` | Rolling direction measured from robot +x toward +y: 0 forward, 90 left. |
| Wheel `direction` | Whether positive calibrated shaft rotation measures travel along (`positive`) or opposite (`negative`) that rolling direction. |
| IMU `invert` | A counterclockwise robot turn must produce positive yaw rate. Keep `false` with aligned BNO08X firmware; physical gyro-Z firmware depends on mounting. |

Check electrical inversion and geometric direction together; avoid changing both
to compensate for the same error. Names such as `left_wheel` are references,
not an assumed geometry: the numeric position and direction define the model.
Two wheels must observe different translation directions and require the gyro
constraint, unless both measure forward: then the model builds only with an
explicit `<LateralMotion assume="zero"/>`, which leaves sideways motion
unmeasured. The supplied three-wheel hardware template also uses the gyro
constraint.

At startup leave the robot stationary and level until `tracking_motion` reports ready. The
templates collect 200 gyro samples for bias calibration; with 50 Hz telemetry
this is roughly four seconds after usable samples begin. BNO08X first needs at
least two seconds and 200 stationary acceleration reports for startup alignment,
so allow about six seconds total. The [bring-up guide](parallel_wheel_bringup.md#5-check-the-sensors-in-this-order)
describes its stationarity checks. Motion can restart calibration. Gravity
supplies up; the Brain's placement supplies field heading. The templates select `planar_motion_integrator`; the
[fusion guide](localization_fusion.md) describes the input and noise settings
for `weighted_planar_fusion`. Do not add a second
independent gyro contribution when it is already included in the wheel model.

## Bring up and calibrate the camera

### Check capture before adding metric calibration

Use the [Raspberry Pi camera software](https://www.raspberrypi.com/documentation/computers/camera_software.html)
to check discovery:

```sh
rpicam-hello --list-cameras
```

Use camera auto-detection or the module's documented overlay. The
[camera backend guide](pi_camera_setup.md) covers device selection, libcamera,
supported capture format, and startup diagnostics. Stop any other program using
the camera before starting Navigatr.

Edit [gatr2_front_camera_uncalibrated.xml](../config/shared/robots/gatr2_front_camera_uncalibrated.xml):
select `Device index`, `Capture width_px`, `height_px`, and `frame_rate_hz`.
The starting selection is 1280 x 960 at 30 Hz, `pixel_format="Y8"`; confirm the
installed camera supports the requested output and rate. Record the actual
camera ID reported in diagnostics, particularly with multiple cameras attached.

```sh
./build/navigatr --config_file="config/override/diagnostics/live_camera_inspection.xml"
```

Through the same SSH tunnel, the camera panel should show images and decoded tag
IDs. Intrinsics and camera mounting are not needed for this 2D check. This profile
does not produce robot localization or measured landmark positions.

### Capture calibration images from the same camera path

Use the included [calibration helper](../tools/calibrate_camera.py), which runs
OpenCV on your computer or on the Pi. It does not become part of the C++ runtime.
OpenCV's [calibration tutorial](https://docs.opencv.org/4.x/dc/dbb/tutorial_py_calibration.html)
explains the camera matrix and five distortion coefficients; its
[pattern guide](https://docs.opencv.org/4.x/da/d0d/tutorial_camera_calibration_pattern.html)
describes printable targets.

Use a flat chessboard with known square size. `--cols` and `--rows` count
**inner corners**, not squares. For example, a board of 10 x 7 squares has
9 x 6 inner corners. Measure the printed square size instead of trusting printer
scaling. Keep the same lens, focus, capture size, rate, and camera/backend settings
for calibration and operation. Changing the sensor crop can invalidate calibration
even when output dimensions match. Focus control is not exposed in the current
XML; a changing-focus camera needs its focus behavior resolved before trusting
one calibration.

Stop Navigatr and, in `live_camera_inspection.xml`, set:

```xml
<Inspection enabled="true" bind="127.0.0.1" port="8765"
            snapshot_hz="20" preview_hz="5"
            preview_quality="100" preview_max_width="1280"/>
```

Use your **actual capture width** for `preview_max_width`, then restart the live
camera profile. The default 640-pixel preview is too small to calibrate a
1280-pixel stream directly. The HTTP image route uses these XML settings;
changing the browser's preview controls or adding width query parameters does
not change that route. It supplies unannotated JPEGs from the actual detector
frames, including frames containing no AprilTags. JPEG is lossy even at quality
100, but setting the width this way avoids resizing. The helper rejects images
whose dimensions do not match the requested calibration dimensions.

On your **viewing computer**, with a checkout of this repository and the SSH
tunnel running, change to `pi/naviGATR`. Create an isolated Python environment:

```sh
python3 -m venv build-camera-tools/venv
./build-camera-tools/venv/bin/python -m pip install opencv-python-headless numpy
```

On **Windows PowerShell**, use:

```powershell
py -3 -m venv build-camera-tools/venv
.\build-camera-tools\venv\Scripts\python.exe -m pip install opencv-python-headless numpy
```

In the following commands, replace `python` with that environment's Python
executable. For the 1280 x 960 example:

```sh
python tools/calibrate_camera.py capture --url "http://127.0.0.1:8765/api/frame.jpg?camera=front_camera" --width 1280 --height 960 --output-dir build-camera-tools/front-images
```

Move the board to different positions, distances, and tilts, including the image
edges. Hold it still and press Enter for each capture; enter `q` when finished.
Aim for 20-30 clear, varied views. The helper requires at least ten distinct
usable images, but image count alone does not establish a good calibration.
It refuses an existing output directory; use a new directory for another run.

For a measured 25 mm square, 9 x 6 inner-corner board:

```sh
python tools/calibrate_camera.py calibrate --images build-camera-tools/front-images --width 1280 --height 960 --cols 9 --rows 6 --square-size-m 0.025 --calibration-id front-1280x960-run1 --frame-id front_camera_engineering --output-dir build-camera-tools/front-calibration
```

Substitute your own board dimensions and square size. The outputs are:

- `calibration.xml`: a complete camera `<Calibration>` fragment.
- `calibration.json`: camera matrix, distortion coefficients, image size,
  reprojection errors, and input provenance for review.

Review rejected views and per-view errors; repeat with better coverage or sharper
images when needed. A low fitting error alone does not verify physical range
accuracy. Keep the images and report associated with the calibration ID.

### Put calibration into the camera XML

In your completed `gatr2_front_camera.xml`:

1. Set `Device` and `Capture` to the exact selection used to collect the images.
2. Replace the whole placeholder `<Calibration>...</Calibration>` with
   `calibration.xml`. Copy it to the Pi if calibration ran on your computer.
3. Keep the `Extrinsic frame_id="front_camera_engineering"` binding, and measure
   the mounting frame as described below.
4. Set the detector family's `detection_size_m` to the measured detector-corner
   edge. For the current field, verify the `tagCircle21h7` family and physical
   size using [field assets](field_assets.md). This is not the carrier-plate width.
   Update the matching `TagMount` sizes in the field definition consistently.

The XML matrix mapping is `fx_px = K[0,0]`, `fy_px = K[1,1]`, `cx_px = K[0,2]`,
and `cy_px = K[1,2]`. Distortion order is `k1, k2, p1, p2, k3`. The helper emits
these named attributes directly. Use the original calibration matrix, not one
computed for a subsequently cropped or undistorted display image. Calibration
board poses returned by the fit do not establish the camera's robot mount.

You can restore the live inspection profile's smaller preview width/quality
after capture. Your main robot profiles use a lower-cost viewer preview while
detection still receives full capture frames.

## Configure camera mounting and field placement

The camera template contains:

```xml
<Frame id="front_camera_engineering" parent_frame_id="robot_body">
    <PoseOfChildInParent x_m="..." y_m="..." z_m="..."
                        roll_deg="..." pitch_deg="..." yaw_deg="..."/>
</Frame>
```

Replace each template token with the measured pose of the **optical center**
relative to your fixed robot origin:

| Attribute | Convention |
|---|---|
| `x_m` | Forward offset; negative behind the origin. |
| `y_m` | Left offset; negative to the right. |
| `z_m` | Height above the robot frame's ground-plane origin. |
| `yaw_deg` | Positive looks left, measured from robot forward. |
| `pitch_deg` | Positive looks down. |
| `roll_deg` | Right-hand rotation about the camera's forward axis; follow the configured Euler convention. |

The configured rotation is `Rz(yaw) * Ry(pitch) * Rx(roll)`. A forward-mounted
camera changes position as the robot turns; the runtime accounts for that offset
using the robot pose at image exposure. Its reported robot x/y remains the robot
origin. See [coordinates](coordinates.md) for the full transform conventions.

In your completed `*_imu_camera_pipeline.xml`, fill:

```xml
<InitialPlacement x_m="..." y_m="..." heading_deg="..."/>
```

This sits inside `Localization`. It describes the robot origin's approximate
starting pose on the field, not the camera location. For the supplied Override
field: origin is the inside bottom-left corner of the audience-view drawing,
+x goes right, +y goes toward the top, and +90 degrees faces +y. Set the real
starting pose each run as needed. With no placement and no placement command,
local odometry alone cannot provide the field prior needed for association.

The main profile's `Inspection/RobotBody` dimensions only affect the drawn box.
Set length, width, height, and the box center's forward/left offset from the
robot origin (`origin_x_m`, `origin_y_m`). They do not substitute for wheel or
camera mounting calibration.

## Run and check the robot

Check your completed XML files for remaining `@...@` values. The camera and
robot files must exist under the names referenced by your main profile.
Place the robot at its configured starting pose, keep it level and stationary
through startup alignment and gyro bias calibration, and run **one** of:

```sh
./build/navigatr --config_file="config/override/diagnostics/three_wheel_imu_camera.xml"
./build/navigatr --config_file="config/override/diagnostics/parallel_wheels_bno08x_camera.xml"
```

Open the same tunneled browser URL. Confirm the source status, localization
readiness, robot position, camera frame sequence, and tag association results.
Startup warnings matter: an unavailable camera or serial link can leave the
process and viewer running while that source supplies no measurements.

Perform short measured checks before relying on estimates:

1. Move forward a known distance: the robot should move in its heading direction
   by that distance. Check a counterclockwise turn, and with three wheels a
   sideways displacement (parallel wheels cannot measure one).
2. Rotate around the robot origin while viewing a stationary landmark: its
   estimated field position should remain approximately fixed. This checks
   mounting offset, wheel geometry, signs, and timing together.
3. View a landmark from several distances and headings. Compare its estimated
   pose against nominal and inspect rejection reasons, frame age, and pose age.
4. If detection work falls behind, inspect worker timing and dropped snapshots.
   Tune detector settings or choose another capture mode; recalibrate when image
   geometry changes. Pose-history coverage must span image-processing latency.

The pipeline exposes `History retention_s`, capacity, and interpolation-gap
limits. A longer retention window does not make an old measurement new. Field
objects retain earlier observations; use the viewer's observation age to judge
freshness. The [camera hardware checks](pi_camera_setup.md#not-verified-on-hardware)
cover exposure timestamps, capture rate, and shutdown behavior that host tests
cannot establish.

### Choose the default main file

To make a completed profile the default for this build:

```sh
cmake -S . -B build "-DNAVIGATR_DEFAULT_CONFIG=config/override/diagnostics/three_wheel_imu_camera.xml"
cmake --build build -j4
./build/navigatr
```

Use the parallel-wheel profile path instead for that robot. `--config_file` overrides the
default for one run. The chosen filename is compiled in; its XML is read each
startup. Editing calibration/configuration requires a restart, not a rebuild.
`./build/navigatr --help` prints the selected default. Ctrl-C stops the service,
workers, and camera cleanly.

## Connect the Brain

The V5 Brain runs a PROS program built on
[communiGATR](../../../docs/communigatr.md). The Brain asks and the Pi answers,
one request at a time, over the Brain's USB port (`pros_usb_link`) or the
HAT's RS-485 link; the Pi never sends unasked.
[Brain link v4](../../../docs/interfaces.md) defines the
requests, sessions, and the timing budget. The Pi side is implemented and host
tested with fake links and clocks; it has not run against a real Brain yet.
The Brain-profiled configs set up both slots as below plus the profile
elements; see [Brain robot profiles](brain_profile.md).

### Pipeline

Every three-wheel and parallel-wheel robot profile selects the brain link in
both slots (the camera inspection profile uses `noop`):

```xml
<CommandCollection type="brain_link">
    <Serial resource_id="brain_uart"/>
    <Reply window_ms="40" turnaround_guard_us="1000"/>   <!-- optional; the defaults -->
</CommandCollection>

<Publishing type="brain_link">
    <Serial resource_id="brain_uart"/>                   <!-- the same resource -->
    <Health fresh_ms="150">                              <!-- optional -->
        <Encoder sensor_id="tracking_encoder_a"/>
        <Gyro sensor_id="robot_imu"/>
        <BiasCal function_id="tracking_motion"/>
    </Health>
    <Field resource_id="override_field"                  <!-- optional -->
           estimate_period_ms="200"/>
    <Pico resource_id="pico_telemetry"/>                 <!-- optional, Pico health bits -->
</Publishing>
```

With a Brain profile, `Health` takes only `fresh_ms`: the encoders and IMU it
reports on follow the running profile. `<BenchImu>` on the CommandCollection
receives the Brain VEX IMU samples, and `<Pico>` there enables the Pico IMU
reinitialize and acquisition restart controls.

Checked when the profile loads:

- `brain_link` command collection and `brain_link` publishing come as a pair on
  the same `Serial` resource. Select `noop` for both to run without a Brain.
- `window_ms > 0` and `0 <= turnaround_guard_us < window_ms * 1000`.
- `1000 / Loop rate_hz <= window_ms / 2`: with the default 40 ms window the
  loop must run at 50 Hz or faster. The supplied profiles run at 100 Hz.
- `Field` names a `field_map` with a `revision`, a `Boundary` and a `wire_id`
  on every landmark; `estimate_period_ms` is positive. See
  [landmarks](landmarks.md#field-documents).

`Reply` bounds when a reply may start: no earlier than `turnaround_guard_us`
after the read that completed the request, and no later than `window_ms` after
the last read of the previous cycle. A reply that would start later is dropped
and the Brain retries. Change the window only together with the Brain's
response timeout (budget formula in the interface document).

Run the executable in its default threaded mode. `--inline` runs world
estimation between a request and its reply, so replies can miss the window;
the executable warns when it is used with the brain link. Each reply blocks the
estimation worker for its airtime at 115200 baud: 5.1 ms for a state reply,
up to 11.1 ms for a full 128-byte document chunk.

### Serial resource

The robot file declares the link:

```xml
<Resource id="brain_uart" type="linux_serial_link">
    <Device path="/dev/ttyAMA5"/>
    <Baud value="115200"/>
    <DriverEnable gpio="6"/>
</Resource>
```

With `DriverEnable` the link is half duplex: DE is low while idle, high only
while the Pi sends a reply, and released once the UART transmitter is empty
plus a two-character guard. Errors and timeouts also release it. The optional
`post_guard_us` and `tx_margin_us` attributes and the failure results are in
[linux_serial_link](../../../docs/navigatr_resources.md#linux_serial_link).

`gpio` is the sysfs number. Some kernels offset it: compare
`cat /sys/class/gpio/gpiochip*/base`; with a base of 512, GPIO6 is
`gpio="518"`. When the GPIO cannot be opened the profile still loads, with a
warning ending in `half-duplex writes will fail`, and every reply then fails
(counted as `tx_errors`).

### Placement and sessions

Only the three-wheel camera profile has an `InitialPlacement`; a Brain SET_POSE
re-anchors it. The other hardware profiles get the starting field pose from
the Brain's SET_POSE when its program initializes. The Pi answers `Pending`
until localization has applied exactly that placement, then `Ok`.

A Brain reboot opens a new session. That withdraws an unapplied SET_POSE, but
it never moves the robot; only a SET_POSE does. A Pi restart or `reset()`
changes `pi_instance`, so the Brain opens a new session.
Localization restarted too, so the robot is unplaced until a placement applies
again: the profile's `InitialPlacement` where configured, otherwise a new
SET_POSE from the Brain program.

With a Brain profile, SET_POSE answers NotReady until a profile is applied, a
new profile leaves the robot unplaced, and a source the profile uses that
drops (stale over 250 ms or restarted) ends the placement: the Brain must place
again. So does motion a model had to discard (a gap past its limit, or
movement while the gyro bias calibrates). A Brain VEX IMU rides on the Brain
link, so with a VEX profile a Brain restart or a link outage over 250 ms needs
a new placement. See
[Brain robot profiles](brain_profile.md#sensor-loss-and-recovery).

### Field documents on the supplied profiles

Every supplied `brain_link` profile publishes the Override field with
`<Field resource_id="override_field" estimate_period_ms="200"/>`. GET_STATE
reports its `map_id` and the newest `estimate_id`, and READ_DOC serves both
documents in chunks.

| Profile | World estimation | Field estimate records |
|---|---|---|
| `brain_profile_usb`, `brain_profile_rs485`, `three_wheel_imu` (`three_wheel_imu_no_correction.xml`), `parallel_wheels_bno08x` (`parallel_wheels_bno08x_no_camera.xml`), `bench_vex_imu`, `bench_vex_imu_usb` | `noop` | every object nominal |
| `three_wheel_imu_camera`, `parallel_wheels_bno08x_camera` | `apriltag` | each landmark nominal until the camera observes it in the current odometry epoch, then observed with its age |

Obstacles (loaders, toggles) are always nominal. See
[landmarks](landmarks.md#field-documents) for the rules and
[field assets](field_assets.md#planning-data) for the collision boxes.

### Check the link

On exit the executable prints the brain link counters once a request has
arrived (`link brain_uart ... requests, replies, ...`). The inspection
snapshot carries the same counters in `diagnostics.estimation.links[]`, the
Brain session in `command`, and in `brain_link` the link state, the state block
the Brain reads, the profile, the wheel readings and the reported path; the
viewer's Brain link panel shows them with a readiness line. See
[inspection](inspection.md). The service log prints lifecycle events as
`event: ...` lines (`journalctl -u navigatr -f`).

| Counter | Meaning |
|---|---|
| `requests` stays 0 | Nothing decodes: device path, baud, wiring, transceiver, or the V5 port. |
| `unanswered` | A request already waiting at the first read after start or reset (applied, not answered; the Brain retries and gets the duplicate answer), or one followed by more bytes in the same cycle. |
| `expired` | The reply window was missed; check `workers.estimation` overruns. |
| `input_pending` | The Brain was still sending when the Pi was about to reply. |
| `tx_errors` | The write failed; check the DriverEnable warning. |
| `late_release` | DE was released later than planned, for example the Pi was preempted. |

### Hardware checks still to do

None of these has been checked on the robot:

- The V5 smart port switches its own RS-485 direction (assumed).
- The sysfs GPIO number of DE on the installed kernel.
- On a scope: DE low while idle, high only during a reply, released after the
  last stop bit.
- `TIOCSERGETLSR` transmitter-empty reporting on `/dev/ttyAMA5`. Without it
  the link falls back to `tcdrain`, which has no deadline of its own.
- Real turnaround and reply latency against the Brain's response timeout.
- If navigatr is killed (SIGKILL, crash) during a reply, DE stays high and
  blocks the Brain until navigatr starts again and drives it low.

## Find the outputs

| Output | Where it goes |
|---|---|
| Robot pose, velocity, attitude status, and recent trail | `RobotStateFeed`; the browser shows localization and pose age. |
| Landmark estimates and their observation/association diagnostics | `FieldSnapshot`; the viewer compares solid observed estimates with ghost nominal objects. |
| Detection images | Camera panel with frame-matched overlays; `/api/frame.jpg?camera=front_camera` supplies the unannotated JPEG. |
| Configuration/geometry and runtime snapshots | Inspection HTTP `/api/hello`, `/api/snapshot`, and live `/ws`; see [inspection](inspection.md). |
| Robot pose, anchor identity, health bits, and the field documents for the Brain | `brain_link` command collection and publishing on `brain_uart` answer each Brain request once and send nothing unasked; positions are millimeters and headings centidegrees on the wire. See [Connect the Brain](#connect-the-brain). |

The supplied hardware profiles select `brain_link` command collection and
publishing and `noop` target resolution. A GET_STATE reply carries the robot
pose, its measurement age, the anchor identity, the configured health bits, and
the ids of the field map and estimate documents, which READ_DOC serves in
chunks with every configured object. Full field heading
is the wire convention; the viewer separately shows heading error from nominal.
See [landmarks and reporting](landmarks.md#brain-output) and the
[wire interface](../../../docs/interfaces.md).

The Pi estimates state and answers requests; Brain code owns robot movement
([investiGATR](../../../docs/investigatr.md) and
[communiGATR](../../../docs/communigatr.md)). The
[bench example](../../../bench/rs485_link/README.md) is a separate
byte-transfer test.

Snapshots and images are not automatically recorded to disk. The calibration
helper explicitly saves its images and reports; runtime estimates otherwise
remain in memory. Stopping or resetting the program clears runtime estimates
and history. It does not write observed displacements back into `field.xml`.

## Troubleshooting

| Symptom | Check |
|---|---|
| Template/token or missing-file error | Complete the selected `.xml.in` files, save `.xml`, and verify each relative reference. |
| Unknown `WorldEstimation` or estimator type | Executable and XML must come from the same source revision; rebuild after source changes. |
| Camera backend not compiled | Configure with `-DNAVIGATR_WITH_LIBCAMERA=ON` on the Pi. |
| Camera unavailable or busy | Startup diagnostic, `rpicam-hello --list-cameras`, selected camera ID, and another process holding capture. |
| Camera works, metric pose unavailable | Intrinsics absent, invalid capture/calibration dimensions, or tag size not supplied. |
| Calibration helper rejects image dimensions | Set XML Inspection preview width to the capture width, restart, and confirm the camera's actual resolution. |
| Calibration finds too few boards | Inner-corner counts, sharpness, complete board visibility, square pattern, varied views. |
| Robot frozen or bias never ready | Pico UART mapping/permissions, firmware output, sensor health, configured channels, and robot motion during calibration. |
| Tags decode but goals stay nominal | InitialPlacement, camera mounting, tag family/size, history availability, and the association rejection reason. |
| Wrong displacement or turn direction | Encoder CPR/sign, wheel radius/geometry, gyro sign, and one shared robot origin. |
| No browser connection | Running inspection service, matching port, SSH tunnel, and another process already using the port. |
| Brain gets no replies | Threaded mode (no `--inline`), the `brain_uart` path and baud, a DriverEnable warning at startup (sysfs `gpio` number, GPIO access), transceiver wiring, then the link counters in [Connect the Brain](#check-the-link). Over USB: the Pi config must be `brain_profile_usb.xml` and exactly one Brain plugged in. |
| Profile refused | The `event: profile ... refused` log line and the viewer name the reason; fix it in `gatr2_robot.h`. An encoder port or IMU the Pi config does not wire is refused, not guessed. |
| Pose keeps becoming invalid | `event: sensor lost: ...` names the source; a VEX profile loses its IMU with the Brain link. |

For the exhaustive parameter list, use [calibration inventory](calibration_inventory.md).

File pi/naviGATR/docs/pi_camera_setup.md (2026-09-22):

# Raspberry Pi camera setup

For the complete robot workflow, use [Set up and run Navigatr](setup.md).
Its [camera calibration section](setup.md#bring-up-and-calibrate-the-camera)
uses the included [OpenCV helper](../tools/calibrate_camera.py) to capture
full-size images through inspection and export the camera XML calibration.

How to build and run the `libcamera_camera` backend on the Pi, what it
assumes about the camera stack, and what has not been checked on hardware.
The backend lives in `src/impl/resources/libcamera_camera.cpp` and is
compiled only with `-DNAVIGATR_WITH_LIBCAMERA=ON`.

Nothing in this backend has run on a Pi yet. The last section lists the
checks to perform before any capture-timing number is trusted.

## Supported stack

- Raspberry Pi OS Bookworm or newer with its matching libcamera packages.
  Record the installed version with `pkg-config --modversion libcamera`;
  no particular Pi package version has been compiled or tested here.
- `rpicam-apps` supplies `rpicam-hello` to list cameras and modes.
- Camera Module 3 (IMX708), HQ Camera (IMX477) and Global Shutter Camera
  (IMX296) all appear through the same pipeline; the backend does not care
  which sensor it is, only which mode it is asked for.
- `CMakeLists.txt` raises the core library to C++20 with the camera option
  enabled so newer libcamera headers can be used; ordinary host builds
  remain C++17.

## Packages

```text
sudo apt update
sudo apt install libcamera-dev rpicam-apps pkg-config cmake g++ libgtest-dev
```

`libcamera-dev` provides the `libcamera` pkg-config module the build looks
up (`pkg-config --modversion libcamera` prints the installed version).
`rpicam-apps` is preinstalled on the desktop image and `rpicam-apps-lite` on
the Lite image; either is enough. `libcamera-tools` (the `cam` utility) is
optional. `libgtest-dev` lets `tests/` use the system gtest instead of
downloading one.

## Enabling the camera

`/boot/firmware/config.txt` ships with `camera_auto_detect=1`, which probes
the official modules. A module that is not auto-detected needs
`camera_auto_detect=0` plus the sensor overlay, for example
`dtoverlay=imx708`, `dtoverlay=imx477` or `dtoverlay=imx296`. Reboot after
changing it.

Confirm detection and note the index:

```text
rpicam-hello --list-cameras
```

Each camera is printed as `<index> : <sensor> [<size> ...] (<device path>)`
followed by its modes. The leading number is the value for
`<Device index="..."/>`. The backend selects `CameraManager::cameras()[index]`
and fails with the enumerated count when the index is out of range. With
one CSI camera both orderings are index 0; with several cameras, or a USB
webcam attached, rpicam-apps lists its own order (USB cameras dropped,
sorted by id), so confirm the choice against the camera id the device
diagnostic prints.

Another process holding the camera causes `acquire()` to fail with
`EBUSY`. Stop that process before starting capture or resetting the device.

## Choosing the capture mode

`rpicam-hello --list-cameras` prints one line per sensor mode, for example
`1536x864 [120.13 fps - (768, 432)/3072x1728 crop]` for the IMX708 or
`1456x1088 [60.38 fps - (0, 0)/1456x1088 crop]` for the IMX296. Rules:

- `width_px` and `height_px` specify the ISP output size. Invalid
  configurations and adjustments to that size or YUV420 format fail open.
  Adjustments to stride, buffer count or colour space are permitted because
  they do not change image geometry. The sensor mode itself is selected by
  libcamera, so calibrate with this backend and capture configuration; a
  matching output resolution alone does not guarantee a matching crop.
- `frame_rate_hz` must not exceed the listed fps of that mode. The backend
  requests a fixed rate through equal `FrameDurationLimits`, after checking
  the configured mode's supported duration range. The sensor may quantize
  the period; measured `FrameDuration` metadata is used when computing the
  exposure uncertainty. Verify the achieved rate on the Pi.
- `pixel_format="Y8"` is the only value the parser accepts. The Pi ISP has
  no greyscale output through libcamera (a request for `R8` is reclassified
  as a raw sensor stream and adjusted to Bayer), so the backend configures
  `YUV420` and publishes the Y plane, row by row through the stream stride,
  as a packed 8-bit image. The U and V planes are never read.
- The intrinsics must be calibrated at this same size and mode. The parser
  refuses a `Calibration` whose `calibrated_width_px`/`calibrated_height_px`
  differ from `Capture`, and a different sensor crop at the same output size
  is a different calibration too.

Four driver buffers are allocated (`bufferCount=4`), each bound to one
request. A frame handed to the runtime is a copy; the driver buffer is
requeued before the copy is published, so buffer reuse can never touch a
frame being processed or displayed. CPU reads are bracketed with
`DMA_BUF_IOCTL_SYNC` START/END operations, as in
[Raspberry Pi's capture application](https://github.com/raspberrypi/rpicam-apps/blob/main/core/rpicam_app.cpp).
Completed-plane bytes-used and stride are checked before copying; truncated
or errored frames are counted and skipped.

## Building

```text
cmake -S . -B build -DCMAKE_BUILD_TYPE=Release -DNAVIGATR_WITH_LIBCAMERA=ON
cmake --build build -j4
ctest --test-dir build --output-on-failure
```

Without the option the binary has no capture backend. Selecting
`type="libcamera_camera"` then fails at configuration time with
`libcamera_camera needs the libcamera backend, which is not compiled into
this binary; configure with -DNAVIGATR_WITH_LIBCAMERA=ON ...`; no device is
constructed and nothing pretends to capture. With the option ON but
`libcamera-dev` missing, `cmake` itself stops at
`pkg_check_modules(LIBCAMERA REQUIRED ...)`.

The host tests never exercise the backend: on a machine without libcamera
the tests assert the explicit configuration error instead.

## Exposure timestamp convention

Every frame carries `exposureAt`, `receivedAt`, `exposure_uncertainty_ms`
and `exposure_time_reliable` (see `src/resources/camera.h`).

Source metadata, read from each completed request:

- `SensorTimestamp` (int64, nanoseconds): libcamera defines this on
  `CLOCK_BOOTTIME`, at exposure of the first active sensor row. See the
  [control definition](https://github.com/raspberrypi/libcamera/blob/main/src/libcamera/control_ids_core.yaml).
  The [Picamera2 manual](https://datasheets.raspberrypi.com/camera/picamera2-manual.pdf)
  instead describes the Pi frame-start interrupt as the first pixel is
  read out. That difference requires a conservative timing bound and an
  eventual physical measurement on the installed camera/kernel.
- `ExposureTime` (int32, microseconds): the exposure the sensor actually
  used for that frame.

What the backend publishes:

```text
exposureAt  = host(SensorTimestamp) + ExposureTime / 2
receivedAt  = host clock when libcamera completed the request
uncertainty = ceil(max(configured period, measured period, exposure)) ms
              + clock sampling / rounding uncertainty
reliable    = true
```

`host()` samples `CLOCK_BOOTTIME` between two host-clock readings for each
completion and maps the sensor timestamp using that correspondence.
`CLOCK_BOOTTIME` includes suspended time while Linux's steady clock does
not; subtracting the steady-clock origin directly would mix the clocks.
The bracket width and millisecond quantization are included in uncertainty.

The bound covers first-row exposure versus readout-start interpretations
and an unknown rolling readout lasting at most a frame period. Half a
period does not cover all of those cases. This is an estimated temporal
interval for a frame, not a calibrated per-row rolling-shutter correction.
Driver timestamps that violate the documented clock domain still require
hardware diagnosis; a source timestamp cannot identify its own clock.

Degradations, all visible in the frame:

- `SensorTimestamp` absent, the clock sample unavailable, or invalid/future
  metadata: `exposureAt = receivedAt`, `exposure_time_reliable = false`.
  Receipt-time fallback does not supply a bounded physical exposure time.
- `ExposureTime` absent: `exposureAt = host(SensorTimestamp)`, reliable,
  uncertainty remains at least one full frame period plus clock conversion.

The consumer side is unchanged: the association looks the robot pose up at
`exposureAt` and the inspection documents show `exposure_host_ms`,
`received_host_ms`, `exposure_uncertainty_ms` and `exposure_time_reliable`
per detection frame. Receipt is never exposure.

Manual exposure and gain are a follow-up. The backend leaves auto exposure
and gain at their defaults; a fixed exposure would use `AeEnable` on
libcamera 0.3/0.4 and `ExposureTimeMode`/`AnalogueGainMode` from 0.5, set in
the request controls (where `Camera::queueRequest` translates them), behind
`LIBCAMERA_VERSION_MAJOR`/`MINOR` guards.

## Running

Live camera inspection before metric calibration, the profile the README
names (uncalibrated camera fragment, no metric pose, detections drawn on
the image):

```text
./build/navigatr config/override/diagnostics/live_camera_inspection.xml
```

The hardware-free demo works on the Pi as well and needs no camera:

```text
./build/navigatr config/demo/synthetic_field_demo.xml
```

Any profile can expose the inspection service without editing it:

```text
./build/navigatr <profile.xml> --inspect-port 8765
```

At startup navigatr prints `warning: <resource path>: <reason>` when the
camera could not open; the resource then reports `unavailable` with that
reason and the robot keeps running without it. The `hello` document lists
each camera with `alive` and `diagnostic`; for a live device the diagnostic
reads
`libcamera <runtime version> (headers <compiled version>); camera <id>;
stream <WxH-YUV420> stride <n> (Y plane as Y8); frames captured N,
replaced M, errors E; request sequence gaps G, frame sequence gaps F`,
with `; error: ...` appended after a failure. `replaced` counts frames a
newer one displaced before the runtime took them (expected to be small at a
loop rate above the frame rate), `frame sequence gaps` counts jumps in the
driver's frame counter (dropped frames), `request sequence gaps` jumps in
libcamera's request counter.

From the viewing computer, forward the loopback port and open the page:

```text
ssh -N -L 8765:127.0.0.1:8765 <user>@<pi-host>
http://127.0.0.1:8765/
```

## Orderly shutdown

Ctrl-C (SIGINT or SIGTERM) stops the inspection service first, then the
estimation worker, then the field worker, then destroys the system. The
camera resource is destroyed with it, in this order: the capture thread is
signalled and joined; `Camera::stop()` cancels the requests still in
flight (they complete as `RequestCancelled` and are dropped); the
`requestCompleted` signal is disconnected; requests are destroyed; the
mapped Y planes are unmapped; the buffers are freed; the camera is released;
the process-wide `CameraManager` stops when the last camera has released.
No thread is ever detached.

`reset()` (an in-process restart) does the stop half, bumps the frame epoch,
releases and reacquires the camera, and restarts sequence numbering at 1.
This also retries an initial open failure or a reconnected device. A
restart that fails leaves the device unavailable with a diagnostic.
Reset must be invoked with System workers stopped, as for other resources.

Unexpected cancelled requests, disconnection, queue failures, CPU access
errors, and no completions for the larger of one second or five configured
frame periods mark capture unavailable. The capture thread exits and reset
can retry. No background automatic reconnect loop is implemented. Failure
cannot clear an error raised by the capture thread during startup.

## Not verified on hardware

Nothing in this backend has run on a Pi. Before relying on it, run these
checks with the live inspection profile and record the results:

1. The camera opens at the configured mode: no `warning:` line at startup,
   `hello.cameras[].alive` true, the diagnostic shows the requested size,
   `YUV420`, and a stride at least the width. Try a size the pipeline must
   adjust and confirm `open()` fails naming that size. Ordinary padded
   stride must continue working.
2. The frame rate matches `frame_rate_hz`: `sources[]` for the camera
   resource and `detection_frames[].sequence` advance at that rate (the
   field worker itself runs at the loop rate and only detects on new
   frames). `FrameDuration` in the metadata should equal the configured
   period; add it to the diagnostic if it does not.
3. `SensorTimestamp` is present: every detection frame shows
   `exposure_time_reliable` true and an uncertainty of at least a frame
   period. False means metadata or clock conversion was unavailable or
   unusable and receipt-time fallback is in use.
4. Exposure latency is plausible: `received_host_ms - exposure_host_ms`
   should be a stable few tens of milliseconds (one frame period plus ISP
   and copy time), never negative and never growing. Then measure the
   actual offset once, for example with an LED switched by a GPIO at a
   known host time, and decide whether `SensorTimestamp` on this kernel
   behaves as readout start or exposure start; adjust the convention above
   if the measured offset says so.
5. Detector throughput at the chosen resolution: `detector_processing_ms`
   in the detection frame and the field worker's `mean_cycle_ms` must stay
   below the frame period, otherwise `workers.field.dropped` climbs and the
   camera path runs at a fraction of the frame rate. Lower the resolution
   or raise `quad_decimate` before trusting timing numbers.
6. No dropped frames at rest: with the robot still, the diagnostic's
   `frame sequence gaps` and `errors` stay at zero over several minutes and
   `replaced` stays small.
7. Restart and shutdown: a `System::reset()` (no runtime trigger exists
   yet; drive it from a small test binary or a temporary hook) produces a
   new epoch and frames keep flowing; also test starting while another
   process owns the camera, releasing it, then resetting. Ctrl-C returns
   promptly with no libcamera warning about unreleased buffers.
8. Two navigatr processes must not share one camera; the second should
   open dead with the `EBUSY` reason, not hang.

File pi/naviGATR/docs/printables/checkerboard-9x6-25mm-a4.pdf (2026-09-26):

naviGATR CAMERA CALIBRATION | A4 landscape

PRINT AT 100% / ACTUAL SIZE. Disable Fit, Shrink and borderless expansion.
10 x 7 squares | 9 x 6 INNER corners | 25 mm squares: measure after printing.

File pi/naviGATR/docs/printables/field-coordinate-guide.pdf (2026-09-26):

# naviGATR FIELD COORDINATES

Top-down audience view | fixed field frame | dimensions from the current field XML

+x

+y

(0, 0) | Audience side

Opposite / top wall

Inside bottom-left is the field origin.

Inside field: 3.5664 m x 3.5664 m

Heading 0 deg | Heading 180 deg
RED WALL | BLUE WALL

### HEADING

0 deg

+90 deg

180 deg

-90 deg

Positive heading = counterclockwise. 0 deg points along field +x.

STARTING ON THE OTHER SIDE The field axes stay fixed.
Change the starting x, y and heading.
Facing inward from opposite walls can
mean 0 deg on one side, 180 deg on the other.

Pose refers to the ROBOT origin near its turning center, not the camera.

Robot axes: +x forward, +y left, +z up. Camera mounting is measured from that robot origin.

Diagram follows config/override/field.xml and docs/coordinates.md. Robot drawings are illustrative.

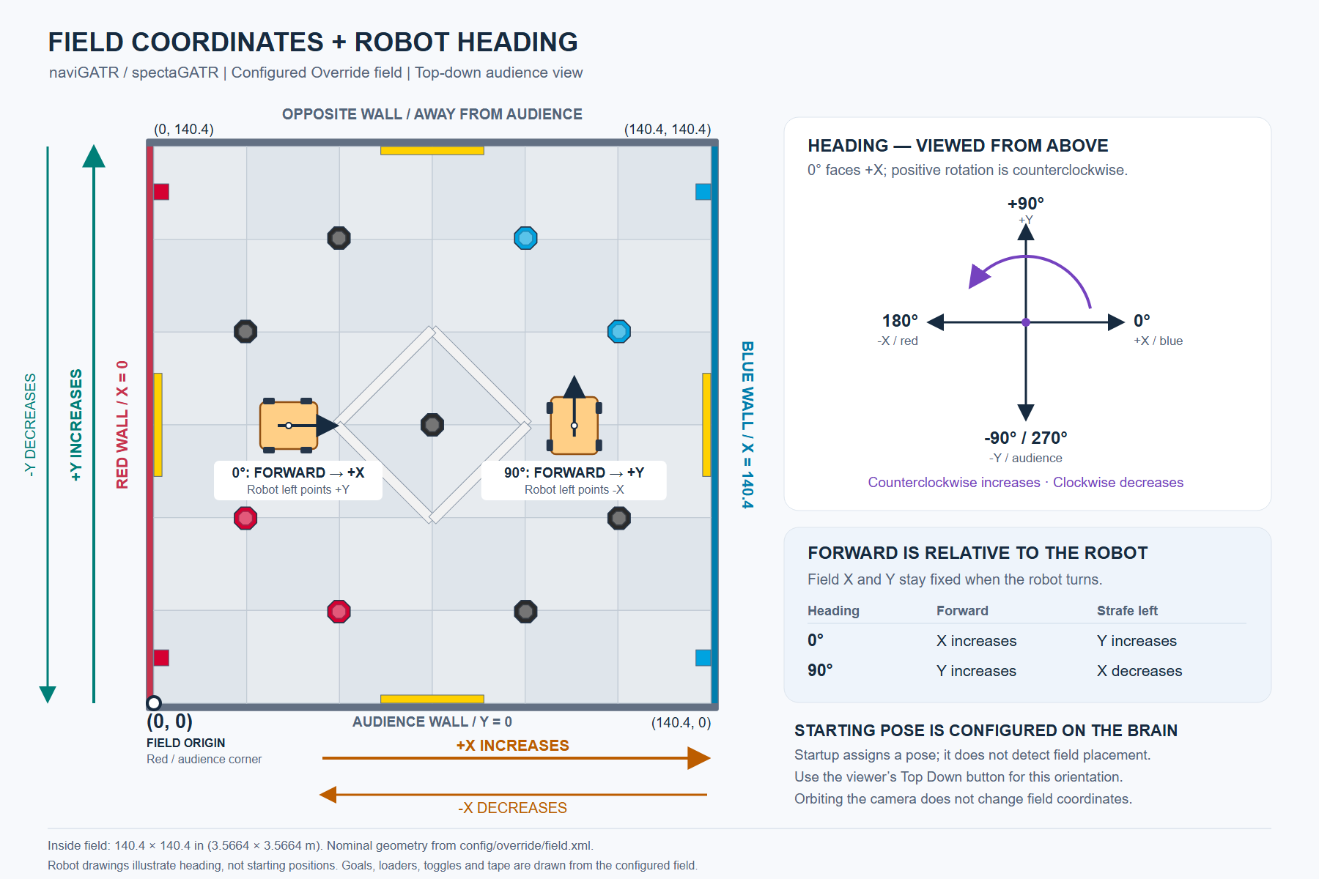
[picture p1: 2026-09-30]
pi/naviGATR/docs/printables/field-conventions-annotated.png

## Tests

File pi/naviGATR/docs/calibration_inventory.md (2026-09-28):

# Calibration inventory

For commands, calibration software, and complete three-wheel camera profiles,
start with [Set up and run Navigatr](setup.md); for the two parallel wheels +
BNO08X profiles, with the [parallel-wheel bring-up](parallel_wheel_bringup.md).

**Brain-profiled configs (the primary path).** With `brain_profile_usb.xml` or
`brain_profile_rs485.xml` the robot's measurements live on the Brain, in
[brain/robot/gatr2_robot.h](../../../brain/robot/gatr2_robot.h), and reach the
Pi as the robot profile; the XML rows below for wheels, encoders and the IMU
sign apply only to the XML-configured profiles. The measurements are the same
ones, split three ways and applied once each ([Brain robot profiles](brain_profile.md#corrections-each-applied-once)):

| Item | Where it goes | How to obtain | Status |
|---|---|---|---|
| Encoder: counts per revolution, polarity (`reversed`), gearing | `gatr2_robot.h`, each `TrackingWheel` | Counts the Pico reports for one encoder shaft turn; roll the wheel along its measuring direction and confirm the travel is positive; gearing is encoder turns per wheel turn | 4000 counts, not reversed, gear 1: defaults to confirm |
| Geometry: radius, mounting position `x`, `y`, measuring angle | same | Loaded radius from a long push (as below); position of the contact point from the robot origin; angle 0 forward, 90 left | radius 0.024 m PROVISIONAL, positions UNMEASURED |
| Empirical: `travel_scale` per wheel | same | The wheel calibration page of `brain/locaGATR` (READ_WHEELS against a measured push, three agreeing trials); see [Brain setup](../../../docs/brain_setup.md#4-per-wheel-calibration) | 1.0 until calibrated; never hides a wrong radius or count |
| IMU source and port, VEX Smart Port, Pico IMU inversion | same (`kSetup`, `kVexImuPort`) | Which IMU is fitted; the Pico chip is fixed by its firmware build | VEX IMU on port 1 for the bench |
| Footprint | same, `kFootprint` | Measure the robot outline about the origin | PLACEHOLDER |
| Start pose | same, `kStartPose` | Tape the starting pose on the field | PLACEHOLDER |
| Stationary window and bias defaults | Pi: `BrainProfile/Calibration`; a profile's calibration window, still rate and still travel override them | Record the robot standing still and compare gyro noise and wheel jitter with `still_rate_dps` (1) and `still_travel_m` (0.001) | defaults, not validated against the real sensors |
| Sensor loss limit | Pi: `BrainProfile/Timing sensor_loss_ms` (250), `on_sensor_loss` | Watch `event: sensor lost` and `motion lost` lines during normal driving; too tight a limit unplaces on ordinary poll gaps. It is also the VEX bench model's longest step. The other limits (`Calibration max_gap_ms` 250, sensor `stale_after_ms` 250, the Pico link's 250 ms gyro accumulator) still end continuity when shorter, so raising it alone never lets a gap go unmeasured | default, not validated against real poll gaps and UART jitter |
| Three-wheel fusion noise | Pi: `BrainProfile/Fusion` | as for `weighted_planar_fusion` below | PLACEHOLDER |

Every measurement the runtime still needs, where it goes, how to get it,
and what depends on it. Status words in this inventory and XML
`calibration_status` attributes are notes for the reader only. The runtime
does not read the labels, require them, or change behavior based on them.
`provisional` describes an unchecked value and `verified` a checked value;
`UNCONFIGURED` can remind the reader that work remains. Actual `.xml.in`
templates and unresolved `@TOKEN@` parameter values are rejected. Required
numbers must be finite and usable, and camera calibration must match the
capture mode. A label cannot supply or validate missing measurements.

Which profile uses which file:

| Profile | Robot fragments | Field | Pipeline |
|---|---|---|---|
| `override/brain_profile_usb.xml`, `override/brain_profile_rs485.xml` | none: devices and wired ports only; the robot comes from the Brain profile | `override/field.xml` (served to the Brain) | inline |
| `override/diagnostics/three_wheel_imu.xml.in` | `gatr2_as5047_imu.xml` | none | `three_wheel_imu_no_correction.xml` |
| `override/diagnostics/parallel_wheels_bno08x.xml` | `gatr2_parallel_wheels_bno08x.xml`, completed from `.xml.in` | `override/field.xml` (display only) | `parallel_wheels_bno08x_no_camera.xml` + shared `parallel_wheels_bno08x_localization.xml` |
| `override/diagnostics/parallel_wheels_bno08x_camera.xml` | `gatr2_parallel_wheels_bno08x.xml` + `gatr2_front_camera.xml` | `override/field.xml` | `parallel_wheels_bno08x_camera.xml` + the same shared localization |
| `override/diagnostics/three_wheel_imu_camera.xml.in` | `gatr2_as5047_imu.xml` + `gatr2_front_camera.xml` | `override/field.xml` | local `three_wheel_imu_camera_pipeline.xml`, completed from `.xml.in` |
| `override/diagnostics/live_camera_inspection.xml` | `gatr2_front_camera_uncalibrated.xml` | `override/field.xml` | `camera_inspection_only.xml` |
| `demo/synthetic_field_demo*.xml` | `synthetic_rig*.xml` (nothing measured) | `override/field.xml` | `synthetic_field_demo.xml` |
| `demo/synthetic_fusion_demo.xml` | `synthetic_rig.xml` (nothing measured) | `override/field.xml` | `synthetic_fusion_demo.xml` |

## Inventory

The parallel-wheel robot template (`gatr2_parallel_wheels_bno08x.xml.in`) has
only `forward_wheel_a`/channel 0 and `forward_wheel_b`/channel 1, both at
measurement angle 0, with tokens `@MEASURE_WHEEL_A_*@`, `@MEASURE_WHEEL_B_*@`,
`@CONFIRM_WHEEL_A_DIRECTION@`, `@CONFIRM_WHEEL_B_DIRECTION@`,
and no other measurement tokens. Encoder CPR is 4000 for default AS5047P
settings and direct 1:1 wheel coupling; verify the physical count and change
it if settings or gearing differ. Encoder `invert` is fixed false so each
wheel has one sign knob, `direction`. IMU `invert` is also false: Pico startup
gravity alignment establishes positive counterclockwise yaw for any fixed
mounting. See the [bring-up guide](parallel_wheel_bringup.md) for the encoder
datasheet and startup checks. The rows below name the three-wheel template's
tokens; its CPR and sign placeholders remain configurable. Each
three-wheel camera main profile also has `Inspection/RobotBody` display
dimensions and body-center offsets relative to the robot origin; these do not
affect estimates.

| Item | Where it goes | How to obtain | Status | Gates |
|---|---|---|---|---|
| Tracking wheel loaded radius, one per wheel | `shared/robots/gatr2_as5047_imu.xml.in`, `Resource[wheel_geometry]/Wheel[left_wheel,right_wheel,rear_wheel]` `radius_m` (`@MEASURE_*_WHEEL_LOADED_RADIUS_M@`) | Push the robot a taped distance of several meters on field tiles, `distance / (counts / CPR) / 2 pi`; repeat both directions, average | placeholder | every wheel profile (all four diagnostics templates); wrong radius scales odometry |
| Tracking wheel position, one per wheel | same element, `position_x_m`, `position_y_m` (`@MEASURE_*_WHEEL_X_M@`, `_Y_M@`) | Measure from the surveyed robot origin to the wheel contact point, +x forward, +y left | placeholder | heading from wheel differences (three-wheel), lateral compensation of the rear wheel; for parallel wheels `position_y_m` is the lever arm that removes turning from forward travel (x unused) |
| Tracking wheel rolling angle and direction | same element, `measurement_angle_deg`, `direction` (`@MEASURE_*_WHEEL_ANGLE_DEG@`, `@CONFIRM_*_WHEEL_DIRECTION@`) | Angle of the rolling direction in the body frame (0 forward, 90 left); push forward or left and confirm the count sign is positive, else `direction="negative"` | placeholder | motion sign; a wrong direction inverts the odometry axis |
| Wheel `calibration_status` | same elements; optional reader annotation | Record measurement progress if useful; for example `verified` once a square drive returns to start within tolerance | reader note | nothing; runtime does not read it |
| Encoder counts per revolution, one per channel | same file, `Sensor[tracking_encoder_a,b,c]/Calibration` `counts_per_revolution` (`@VERIFY_ENCODER_*_CPR@`) | AS5047 configuration as decoded by the Pico (see `pico/aggreGATR/src`), confirmed by ten hand turns of the wheel | placeholder | distance scale, with radius |
| Encoder invert, one per channel | same, `invert` (`@CONFIRM_ENCODER_*_INVERT@`) | Turn the wheel forward, confirm counts increase; `true` if they decrease | placeholder | motion sign |
| IMU yaw sign | same file, `Sensor[robot_imu]/Calibration` `invert` (`@CONFIRM_IMU_CCW_POSITIVE_INVERT@`) | Rotate the robot counterclockwise from above; `gyro_z` must read positive, else `true` | placeholder | heading constraint sign; gyro bias calibration is automatic (a qualified stationary window, `bias_samples` samples over `window_ms`) |
| Camera device index | `shared/robots/gatr2_front_camera.xml.in`, `Resource[front_camera_device]/Device` `index` (`@SELECT_CAMERA_INDEX@`) | `rpicam-hello --list-cameras` on the Pi | placeholder (0 selected in `gatr2_front_camera_uncalibrated.xml`) | the camera opens at all |
| Capture mode and rate | same, `Capture` `width_px`, `height_px`, `frame_rate_hz` (`@SELECT_CAPTURE_*@`); `pixel_format` is fixed `Y8` | Pick a listed sensor mode; the calibration must be done at this same mode, the resource refuses a mismatch | placeholder (1280 x 960 at 30 Hz selected, not calibrated, in the uncalibrated fragment) | frame timing budget; the live inspection profile runs on the selection alone |
| Intrinsics | same, `Calibration/Intrinsics` `calibrated_width_px`, `calibrated_height_px`, `fx_px`, `fy_px`, `cx_px`, `cy_px`, `k1`, `k2`, `p1`, `p2`, `k3` (`@CALIBRATED_*@`), model fixed `brown_conrady` | Chessboard or ChArUco calibration at the capture mode from frames captured on the Pi (OpenCV `calibrateCamera` on a laptop is fine); 20+ views covering the corners | placeholder (absent by design in the uncalibrated fragment) | any metric tag pose: without it every decode is 2D, association rejects it, no landmark evidence |
| Calibration RMS and run id | same, `rms_reprojection_px` (`@CALIBRATION_RMS_PX@`), `Calibration` `calibration_id` (`@CALIBRATION_RUN_ID@`) | Reported by the calibration; name the run by date | placeholder | numeric calibration metadata; an optional `calibration_status` label has no runtime effect |
| Camera mount pose | same file, `Resource[robot_geometry]/Frame[front_camera_engineering]/PoseOfChildInParent` `x_m`, `y_m`, `z_m`, `roll_deg`, `pitch_deg`, `yaw_deg` (`@MEASURE_CAMERA_*@`), `calibration_status` | Measure from the robot origin to the optical center (+x forward, +y left, +z up; positive pitch looks down, positive yaw looks left); check by observing a tag at a taped field pose and comparing the implied landmark pose in the viewer | placeholder (the uncalibrated fragment declares no frame) | `tag_mount_association` needs the camera frame in the robot frame map; the camera diagnostic profiles |
| Detector corner size | same file, `Resource[tag_detector]/Family` `detection_size_m` (`@MEASURE_DETECTOR_CORNER_EDGE_SIZE_M@`); also every `TagMount` in `override/field.xml` | Measure the printed pattern side on a physical goal; the corner square is 5/9 of it for tagCircle21h7 | provisional (0.01761272 inferred from the CAD, see [field assets](field_assets.md)) | range scale of every metric tag pose; change the field file and the detector together |
| Tag family | same `Family` `name`; every `TagMount` `family` | Run `live_camera_inspection.xml` at a goal and see whether ids 0-4 decode as tagCircle21h7 | provisional (inferred; the manual never names it) | any decode at all |
| Initial robot placement | `Localization/InitialPlacement` in the local `override/diagnostics/*_imu_camera_pipeline.xml.in` templates; the parallel-wheel and Brain-profiled configs have none and take the pose from the Brain (`kStartPose` in `brain/robot/gatr2_robot.h`) | Tape the starting pose on the field, enter the robot origin's field coordinates (x, y, heading counterclockwise from +x) | per run; camera pipeline templates have required placement tokens, synthetic demos supply their own placement | field poses and association priors: without placement localization stays odometry-only and no landmark evidence is accepted |
| Field map geometry | `override/field.xml`, nine `NominalPose` and 36 `TagMount` elements | Nominal CAD positions are sufficient for association; optional physical checks can improve nominal accuracy. Competition displacement is estimated rather than configured in advance | provisional reader annotation | nominal association priors; the association translation gate (0.5-0.75 m) tolerates placement differences |
| BNO08X startup up axis | Pico `GravityAlignment`, automatic at startup and IMU reset | Keep the robot level and stationary: at least 2 s and 200 acceleration samples; fresh gyro XYZ at most 0.10 rad/s, acceleration magnitude 9.80665 +/- 0.5 m/s^2, vector variation at most 0.25 m/s^2. On localization startup, Pi bias collection adds a stationary window (2 s by default) after yaw becomes available; an IMU restart the Pi can see (a Pico reboot, or an IMU epoch change from firmware that reports one) invalidates the Pi bias and repeats it. | automatic; hardware validation pending | projected yaw availability; permits sideways/upside-down fixed IMU mounting |
| Attitude source | would be a `Sensor type="attitude_channel"` bound to a resource output, an `Observation type="attitude_reference"` and an `Estimator/Attitude` reference (see `synthetic_rig.xml` and `synthetic_field_demo.xml`) | No live attitude report exists in firmware. BNO08X acceleration at 100 Hz and uncalibrated gyro XYZ at 200 Hz supply a fixed startup up axis and projected yaw only; ASM330 reads physical gyro Z. Pico `SensorSample` carries `enc[3]`, `gyro_z` and optional `accel[2]` (`translaGATR/frames.h`); the reserved accel fields remain absent. Live tilt needs additional acquisition and protocol work; see [attitude follow-up](attitude_firmware_followup.md). The runtime attitude path is exercised by the synthetic rig. | absent | measured tilt in association (`Attitude policy="assume_level"` otherwise) and the viewer's attitude badge; nothing else |
| Camera exposure timestamps | no configured value; `CameraFrameData.exposureAt`, `exposure_uncertainty_ms`, `exposure_time_reliable` from the libcamera backend | On the Pi, compare the reported exposure time with the host monotonic clock and a known event (a flashed LED), confirm the uncertainty bound and the latency; see [Pi camera setup](pi_camera_setup.md) | untested on hardware | pose-at-exposure lookups (`History max_interpolation_gap_ms`) and every association decision |
| Odometry and gyro noise | `Localization/Estimator[weighted_planar_fusion]/Motion/Noise` and `Heading/Noise` in a pipeline fragment (`synthetic_fusion_demo.xml` carries placeholders); units in [localization fusion](localization_fusion.md) | Wheel translation and rotation error per meter and per radian from repeated known-path drives against tape; gyro angle random walk and residual bias from a long stationary recording after `bias_samples` calibration | placeholder | the fusion weights and the reported `odom_covariance`; the pose itself still follows the wheels and gyro |
| Pi link parameters | `gatr2_as5047_imu.xml.in`, `gatr2_parallel_wheels_bno08x.xml.in`, `Resource[pico_uart]`, `Resource[brain_uart]` | Already known: `/dev/ttyAMA0` 115200, `/dev/ttyAMA5` 115200 (`docs/hardware.md`) | verified | serial transport |
| Brain link DriverEnable and reply timing | same files, `Resource[brain_uart]/DriverEnable` `gpio` (optional `post_guard_us`, `tx_margin_us`); the pipeline's `CommandCollection[brain_link]/Reply` `window_ms`, `turnaround_guard_us` (defaults 40 ms, 1000 us) | GPIO6 is the HAT's DE pin (`docs/hardware.md`); `gpio` is its sysfs number, so compare `/sys/class/gpio/gpiochip*/base` on the installed kernel (a base of 512 gives 518). On a scope, DE low while idle and high only during a reply; replies inside the Brain's response timeout. See [Connect the Brain](setup.md#connect-the-brain) | pin known; sysfs number, turnaround and timing not validated on hardware | every Brain reply; an unreachable GPIO is a startup warning and every reply fails |
| Field object wire ids and collision boxes | `override/field.xml`: `wire_id` on every `Landmark` and `Obstacle`, `CollisionBox` sizes, `Boundary`, `revision`; regenerate `brain/operaGATR/include/field_references.h` after an edit | Collision boxes from the manual and CAD ([field assets](field_assets.md#planning-data)); measure the goal base and the loader and toggle footprints on a real field | provisional, derived not measured | Brain planning obstacles and named references |

Not in the table because nothing in the runtime consumes them yet: the
loader, toggle and tape positions (display only, from the manual), and the
robot body size in `Inspection/RobotBody` (cosmetic).

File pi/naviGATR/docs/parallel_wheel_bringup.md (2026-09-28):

# Bring up two parallel wheels + BNO08X

Pi HAT v2, a Raspberry Pi Pico, a GY-BNO08X IMU, and two tracking wheels that
both measure forward/backward travel, configured in Pi XML. Get localization
working first with profile A, then add the camera with profile B. Neither
profile uses a third wheel or encoder channel 2.

**The primary path is a Brain profile.** The same hardware runs from
`brain_profile_usb.xml` or `brain_profile_rs485.xml` with a Brain profile of
two forward wheels and the Pico IMU: the Pi then builds the same models
(`tracking_wheel_motion` with the heading constraint and zero lateral motion)
from the Brain's description, and a geometry change is a Brain upload. See
[Brain robot profiles](brain_profile.md). The current Brain programs always
send a profile; these XML profiles refuse it (reason "not accepted"), and the
Brain then refuses to place, so use them with a Brain client built without a
profile or for camera work. The wiring, Pico and sensor-check sections below
apply to both paths.

| Profile | Main file | Adds |
|---|---|---|
| A: wheels + IMU | [parallel_wheels_bno08x.xml](../config/override/diagnostics/parallel_wheels_bno08x.xml) | Localization, pose history, viewer, field map for display. World estimation is the registered noop. |
| B: A + camera | [parallel_wheels_bno08x_camera.xml](../config/override/diagnostics/parallel_wheels_bno08x_camera.xml) | The front camera, calibration, mount, AprilTag detector and world estimation. |

Both profiles include one shared [localization fragment](../config/shared/pipelines/parallel_wheels_bno08x_localization.xml)
and one [robot description](../config/shared/robots/gatr2_parallel_wheels_bno08x.xml.in),
so wheel and IMU calibration is entered once.

## What runs now and what waits for measurements

| File | State |
|---|---|
| `config/override/diagnostics/parallel_wheels_bno08x.xml` | Complete. Resolves once the robot file below exists; until then it fails and names that file. |
| `config/override/diagnostics/parallel_wheels_bno08x_camera.xml` | Complete. Also needs the camera file below and a libcamera build. |
| `config/shared/pipelines/parallel_wheels_bno08x_*.xml` | Complete. No measured values in them. |
| `config/shared/robots/gatr2_parallel_wheels_bno08x.xml.in` | **Template.** Wheel radius, offsets and directions need measurements. Default AS5047P CPR is 4000; aligned IMU yaw uses `invert="false"`. |
| `config/shared/robots/gatr2_front_camera.xml.in` | **Template.** Camera selection, intrinsics and mounting are unmeasured. |
| `config/demo/synthetic_field_demo.xml` | Runnable now without hardware, for checking the build and the viewer. |
| Pico firmware `hat2_bno08x` | Builds. Not yet run on the robot. |

Nothing here has been validated on hardware. The software tests use synthetic
data only.

## 1. Wiring

Encoders, on the HAT:

| Channel | HAT connector | Pico pins |
|---|---|---|
| 0 | J2 | A = GP0 (pin 1), B = GP1 (pin 2) |
| 1 | J3 | A = GP2 (pin 4), B = GP3 (pin 5) |

BNO08X, by the module's printed labels:

| Module | Pico | Route |
|---|---|---|
| VCC | 3.3 V | J7 pin 7 |
| GND | GND | J7 pin 1 or 8 |
| SCL (SPI SCK) | GP10, pin 14 | J7 pin 5 |
| SDA (SPI MISO) | GP8, pin 11 | J7 pin 3 |
| ADO (SPI MOSI) | GP11, pin 15 | J7 pin 4 |
| CS | GP9, pin 12 | J7 pin 6 |
| INT | GP22, pin 29 | J7 pin 2 |
| RST | GP12, pin 16 | added wire |
| PS0/WAKE | GP13, pin 17 | added wire |
| PS1 | 3.3 V | added wire |

The Pico-Pi UART is unchanged: Pico TX GP16 (pin 21), RX GP17 (pin 22), 115200
baud, `/dev/ttyAMA0` on the Pi. Pin definitions live in
[pico/aggreGATR/src/board.h](../../../pico/aggreGATR/src/board.h).

## 2. Build and flash the Pico

From the repository on the development computer:

```sh
cd pico/aggreGATR
pio run -e hat2_bno08x
```

Flash it by hand. Either hold BOOTSEL while plugging in the Pico's USB and copy
`pico/.pio/build/hat2_bno08x/firmware.uf2` onto the `RPI-RP2` drive, or run
`pio run -e hat2_bno08x --target upload` with the board connected. The
`hat2_asm330` environment builds the older ASM330 IMU instead.

Flash this build even if the Pico already has firmware. The previous firmware
gated every frame on `Serial1.availableForWrite() >= n`, which is always false
on this Arduino core, so it never transmitted.

The BNO08X supplies acceleration at 100 Hz and uncalibrated gyro XYZ at 200 Hz.
During a stationary, level startup, the Pico learns the up direction in the
sensor's frame, then projects gyro XYZ onto it. Sideways and upside-down fixed
IMU mountings work with the same positive counterclockwise yaw convention.
Each 50 Hz frame carries the mean projected rate, with bias left for the Pi
to calibrate. During alignment, missing data or resets, frames keep flowing
with the gyro bit clear. Reset recovery repeats alignment. No live roll or
pitch is sent, and the fixed axis does not compensate dynamic rocking.

## 3. Fill in the robot description

On the Pi, from `pi/naviGATR`:

```sh
cp -n config/shared/robots/gatr2_parallel_wheels_bno08x.xml.in config/shared/robots/gatr2_parallel_wheels_bno08x.xml
```

Edit the `.xml` and replace every `@...@` value. Never put zero in just to make
it parse. First choose the robot origin: the point the reported pose refers to.
The drivetrain's turning center is best, because a turn in place then leaves
the reported position still. Axes are +x forward, +y left.

| Token | Value |
|---|---|
| `MEASURE_WHEEL_A_Y_M`, `MEASURE_WHEEL_B_Y_M` | Lateral offset of each wheel's contact point from the origin, left positive. This is the lever arm that removes turning from the wheel travel, so measure it carefully. |
| `MEASURE_WHEEL_A_X_M`, `MEASURE_WHEEL_B_X_M` | Forward offset. It does not affect the forward-only solve, but record it. |
| `MEASURE_WHEEL_A_LOADED_RADIUS_M`, `..._B_...` | Effective rolling radius under load. Start from calipers, then tune it with the push test below. |
| `CONFIRM_WHEEL_A_DIRECTION`, `..._B_...` | `positive` when the count increases as the robot drives forward, else `negative`. This is the only sign knob per wheel; encoder `invert` stays false. |

Wheel A is channel 0 (J2), wheel B is channel 1 (J3).
Both encoders are configured for **4000 counts/revolution**, the AS5047P
default with x4 decoding and direct 1:1 wheel coupling
([datasheet, page 19](https://www.mouser.com/datasheet/2/588/AS5047P_DS000324_3_00-1843440.pdf)).
Change this value if the encoder settings or gearing differ; confirm it in the
one-revolution test. Keep IMU `invert="false"`: the Pico's gravity projection
already establishes positive counterclockwise yaw.

## 4. Build and run profile A

On the Pi, from `pi/naviGATR`:

```sh
cmake -S . -B build -DCMAKE_BUILD_TYPE=Release -DNAVIGATR_WITH_LIBCAMERA=ON
cmake --build build -j4
./build/navigatr --config_file=config/override/diagnostics/parallel_wheels_bno08x.xml
```

Use `-j2` if the Pi runs out of memory. Profile A does not need libcamera, but
building with it now avoids a rebuild for profile B. Run the threaded default,
not `--inline`, when the Brain is connected.

Open the viewer from the development computer through SSH:

```sh
ssh -N -L 8765:127.0.0.1:8765 <user>@<pi-host>
```

Then browse to `http://127.0.0.1:8765/`. The field and the nominal landmark
positions (labelled "nominal") show immediately. With no Brain placement yet,
the robot is drawn grey and labelled "not placed", and the status bar reads
"not placed: odometry frame": that pose is odometry from where localization
started, drawn from the field origin, not a field position. The camera panel
reads "no camera configured".

## 5. Check the sensors, in this order

1. **Hold stationary and level for alignment and bias.** Wait until the
   localization table shows `tracking_motion` ready, normally about 6 s.
   Pico alignment requires at least 2 s and 200 acceleration samples with
   quiet, fresh gyro XYZ. Its checks allow gravity magnitude within 0.5 m/s^2
   of 9.80665, acceleration-vector variation up to 0.25 m/s^2, and gyro magnitude
   up to 0.10 rad/s; motion restarts collection. The Pi then collects 200 yaw
   samples, about 4 s at 50 Hz, restarting its bias collection if the wheels
   move. Until then no usable pose is produced. If it never becomes ready,
   check `robot_imu` freshness, IMU wiring, RST/PS0 wires and firmware.
2. **Encoder counts and wheel signs.** Lift the robot so the IMU stays still.
   Spin only wheel A forward by hand: x must increase (by half that wheel's
   travel, since the two wheels are averaged). If x decreases, flip
   `CONFIRM_WHEEL_A_DIRECTION`. Repeat for wheel B. If nothing moves, check the
   encoder's sensor state in the sources table and the J2/J3 wiring.
3. **CPR.** Still lifted, turn one wheel exactly one marked revolution: x
   should change by pi times the radius. Check the radius, gearing and encoder
   settings if the result differs substantially from this prediction.
4. **IMU sign.** On the floor, rotate the robot counterclockwise seen from
   above by about 90 degrees: heading must increase by about 90. If it
   decreases, check that the aligned BNO08X firmware is flashed, `invert` is
   `false`, and startup alignment happened with the robot level and still.
5. **Rotation and wheel offsets.** Turn in place several full turns about the
   origin. The reported position should stay nearly still. If it swings around a
   circle, the lateral offsets or a wheel sign are wrong.
6. **Translation and radius.** Push the robot straight 2 m along a tape: x
   should read 2.000 m with heading unchanged. Scale the radius by true/reported
   distance and repeat.
7. **Known limitation.** Push the robot sideways: the pose does not move. Both
   wheels measure forward only, so the localization assumes zero sideways
   motion. Sideways slip or pushing is not measured and is not corrected; the
   camera does not fix it either, because landmark estimates are never fed back
   into localization.

Restart navigatr after editing the XML. Each start calibrates the gyro bias
again; restarting the Pico or BNO08X also repeats startup gravity alignment.
A Pico reboot, or an IMU restart that the Pico firmware reports (its IMU
epoch), invalidates the Pi's bias and collects it again; older firmware shows a
hub reset only as a gap, which keeps the old bias. After remounting the IMU,
restart it and localization, then repeat the level, stationary startup. The
Brain's placement supplies field heading because gravity only defines up.

## 6. Brain placement

The profiles have no `InitialPlacement`. The Brain sends the robot's starting
FIELD pose (x, y, heading) over the brain link when its program initializes,
and waits until the Pi reports that localization applied it. From then on the
viewer draws the robot orange at its field pose. A new Brain session (a Brain
reboot) never moves the robot and never resumes an old movement; only a new
placement relocates it.

The field axes come from [field.xml](../config/override/field.xml) and never
change with the starting side. Starting on the other side means sending a
different x, y and heading, not mirroring the axes. The Brain programs'
starting pose is `kStartPose` in
[brain/robot/gatr2_robot.h](../../../brain/robot/gatr2_robot.h) (meters,
degrees counterclockwise from field +x). It is a placeholder until you measure
where the robot sits. See [Brain setup](../../../docs/brain_setup.md) for the
Brain side.

In profile A world estimation is off: the field documents the Brain reads keep
every landmark at its nominal pose, so landmark-relative moves use the nominal
map. A nominal landmark drawn in the viewer is never an observation.

## 7. Add the camera: profile B

Fill in the camera description the same way:

```sh
cp -n config/shared/robots/gatr2_front_camera.xml.in config/shared/robots/gatr2_front_camera.xml
```

It needs the capture mode, the lens calibration and the camera mount relative
to the same robot origin. [Camera setup](pi_camera_setup.md) and
[setup](setup.md#bring-up-and-calibrate-the-camera) describe capture checks and
calibration. Then run:

```sh
./build/navigatr --config_file=config/override/diagnostics/parallel_wheels_bno08x_camera.xml
```

The localization is byte for byte the same as profile A. The camera panel shows
the preview with tag overlays bound to the exact frame they were decoded from.
The field view adds solid "est." landmarks for observed estimates next to the
nominal ghosts. Each detection uses the robot pose from the pose history at the
frame's exposure time and the configured camera mount. Missing tilt is assumed
level; the Pico sends no roll or pitch. Detection runs in its own worker, so a
slow or failed camera never stalls localization; a camera fault shows in the
sources table.

The Brain reads every landmark from the field documents that the Publishing
section of
[the camera pipeline](../config/shared/pipelines/parallel_wheels_bno08x_camera.xml)
serves. A landmark stays nominal until the camera observes it; see
[landmarks](landmarks.md#field-documents).
Nominal map poses are never accepted as observed landmarks by default.

A camera configured with world estimation off still shows its preview, marked
"preview only, detection not run".

## Troubleshooting

- **No encoder or gyro data.** Check `pico_uart` in the sources table and
  reflash the firmware (section 2).
- **`tracking_motion` never ready.** Startup alignment or bias calibration is
  incomplete, or an IMU report is stale. Keep the robot level and stationary
  for about 6 s and check `robot_imu`.
- **Pose jumps or drifts during turns.** Check the lateral offsets and wheel
  signs with the turn-in-place test.
- **Heading drifts while still.** The robot moved during calibration; restart
  while holding it still.

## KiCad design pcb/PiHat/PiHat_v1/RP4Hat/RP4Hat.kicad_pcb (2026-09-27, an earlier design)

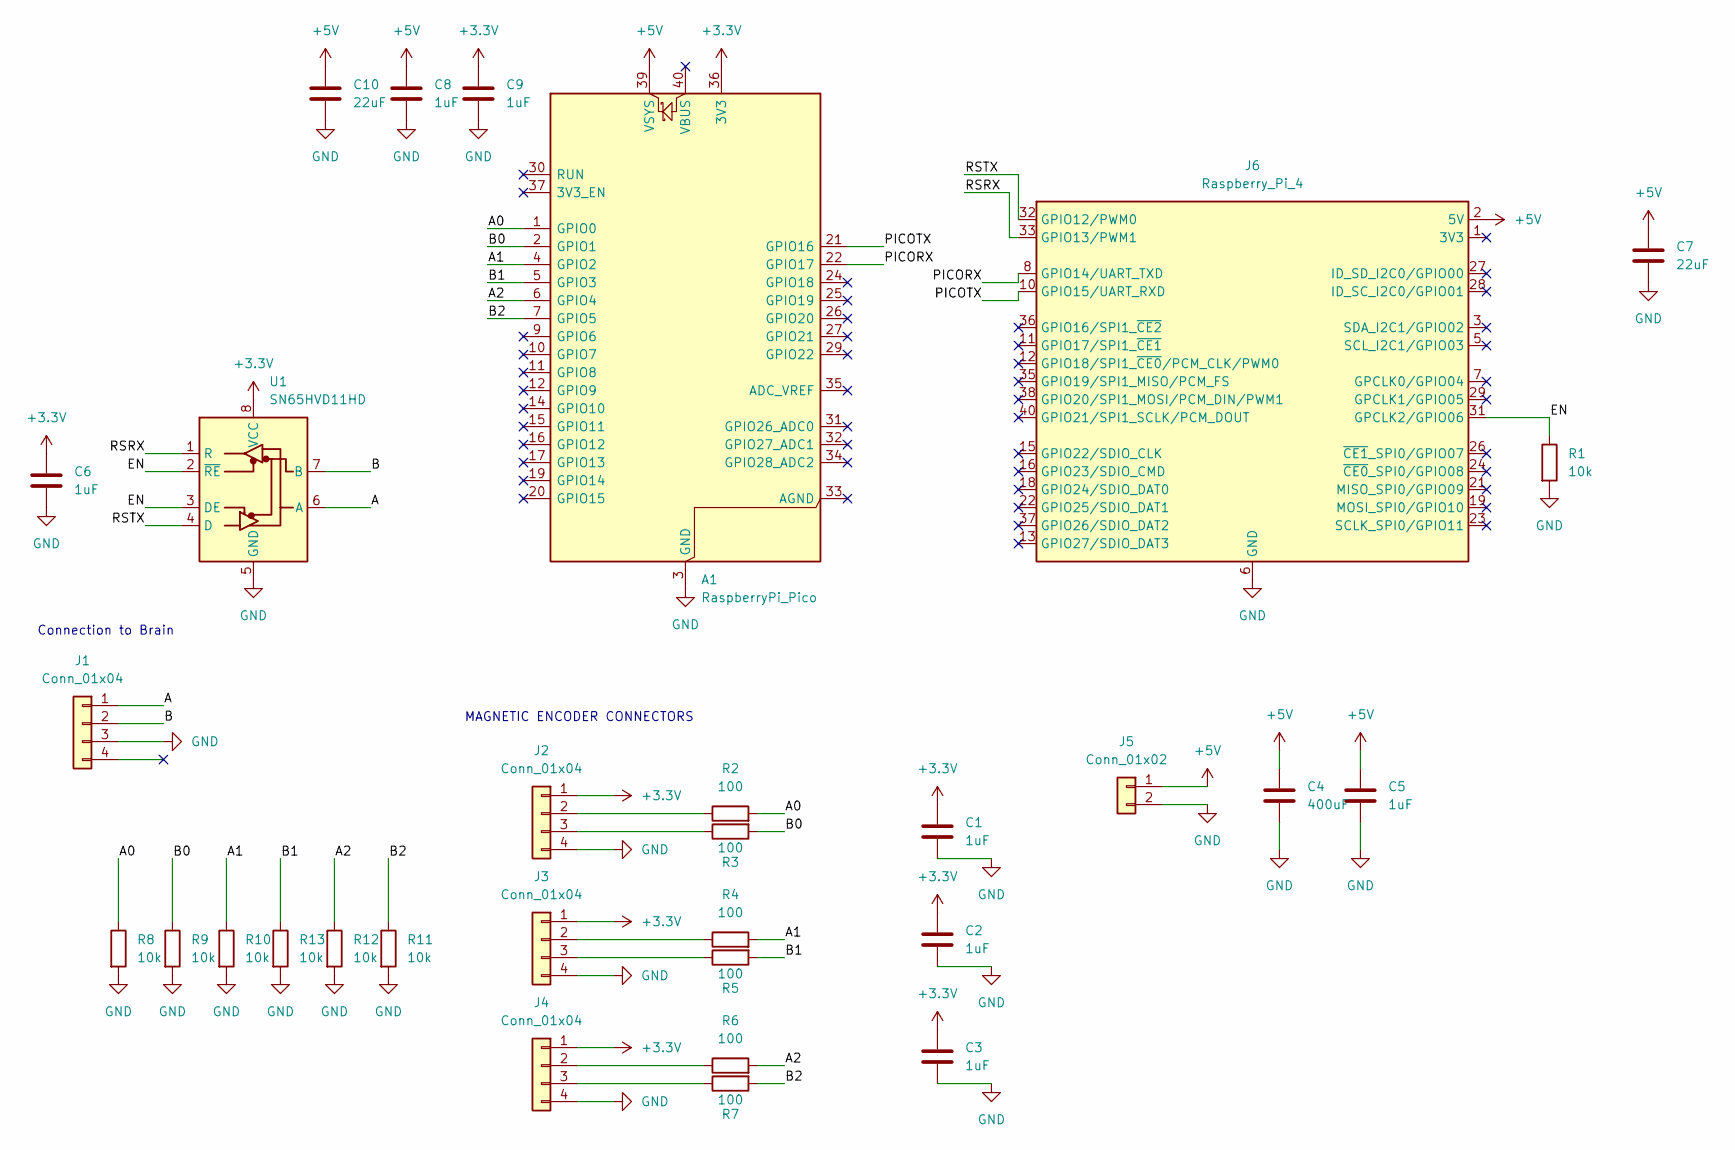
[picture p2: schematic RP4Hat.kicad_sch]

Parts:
A1: RaspberryPi_Pico; RaspberryPi_Pico_Common_Unspecified
C1, C2, C3, C5, C6, C8, C9: 1uF; C_0805_2012Metric_Pad1.18x1.45mm_HandSolder
C4: 400uF; CP_Radial_D8.0mm_P3.50mm
C7, C10: 22uF; C_0805_2012Metric_Pad1.18x1.45mm_HandSolder
J1, J2, J3, J4: Conn_01x04; JST_XH_B4B-XH-A_1x04_P2.50mm_Vertical
J5: Conn_01x02; JST_XH_B2B-XH-A_1x02_P2.50mm_Vertical
J6: Raspberry_Pi_4; PinSocket_2x20_P2.54mm_Vertical
R1, R8, R9, R10, R11, R12, R13: 10k; R_0805_2012Metric_Pad1.20x1.40mm_HandSolder
R2, R3, R4, R5, R6, R7: 100; R_0805_2012Metric_Pad1.20x1.40mm_HandSolder
U1: SN65HVD11HD; SOIC-8_3.9x4.9mm_P1.27mm

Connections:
+3.3V: A1.36 (3V3), C1.1, C2.1, C3.1, C6.1, C9.1, J2.1, J3.1, J4.1, U1.8 (VCC)
+5V: A1.39 (VSYS), C4.1, C5.1, C7.1, C8.1, C10.1, J5.1, J6.2 (5V), J6.4 (5V)
/A: J1.1, U1.6 (A)
/A0: A1.1 (GPIO0), R2.2, R8.1
/A1: A1.4 (GPIO2), R4.2, R10.1
/A2: A1.6 (GPIO4), R6.2, R12.1
/B: J1.2, U1.7 (B)
/B0: A1.2 (GPIO1), R3.2, R9.1
/B1: A1.5 (GPIO3), R5.2, R13.1
/B2: A1.7 (GPIO5), R7.2, R11.1
/EN: J6.31 (GPCLK2/GPIO06), R1.1, U1.2 (~RE), U1.3 (DE)
/PICORX: A1.22 (GPIO17), J6.8 (GPIO14/UART_TXD)
/PICOTX: A1.21 (GPIO16), J6.10 (GPIO15/UART_RXD)
/RSRX: J6.33 (GPIO13/PWM1), U1.1 (R)
/RSTX: J6.32 (GPIO12/PWM0), U1.4 (D)
GND: A1.3 (GND), A1.8 (GND), A1.13 (GND), A1.18 (GND), A1.23 (GND), A1.28 (GND), A1.38 (GND), C1.2, C2.2, C3.2, C4.2, C5.2, C6.2, C7.2, C8.2, C9.2, C10.2, J1.3, J2.4, J3.4, J4.4, J5.2, J6.6 (GND), J6.9 (GND), J6.14 (GND), J6.20 (GND), J6.25 (GND), J6.30 (GND), J6.34 (GND), J6.39 (GND), R1.2, R8.2, R9.2, R10.2, R11.2, R12.2, R13.2, U1.5 (GND)
unnamed: J2.2, R2.1
unnamed: J2.3, R3.1
unnamed: J3.2, R4.1
unnamed: J3.3, R5.1
unnamed: J4.2, R6.1
unnamed: J4.3, R7.1

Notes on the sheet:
MAGNETIC ENCODER CONNECTORS
Connection to Brain

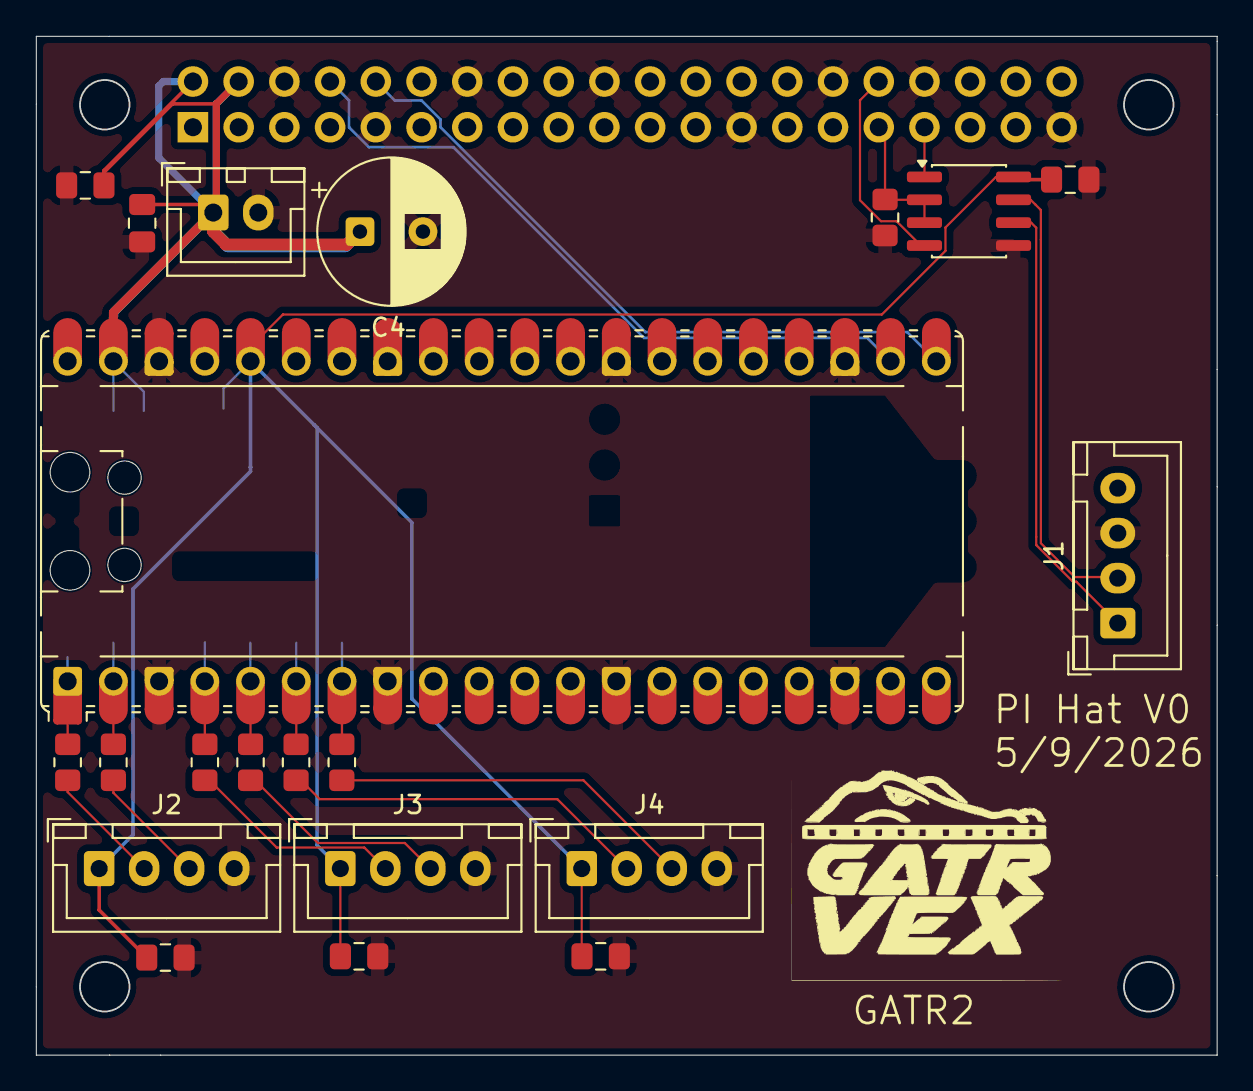
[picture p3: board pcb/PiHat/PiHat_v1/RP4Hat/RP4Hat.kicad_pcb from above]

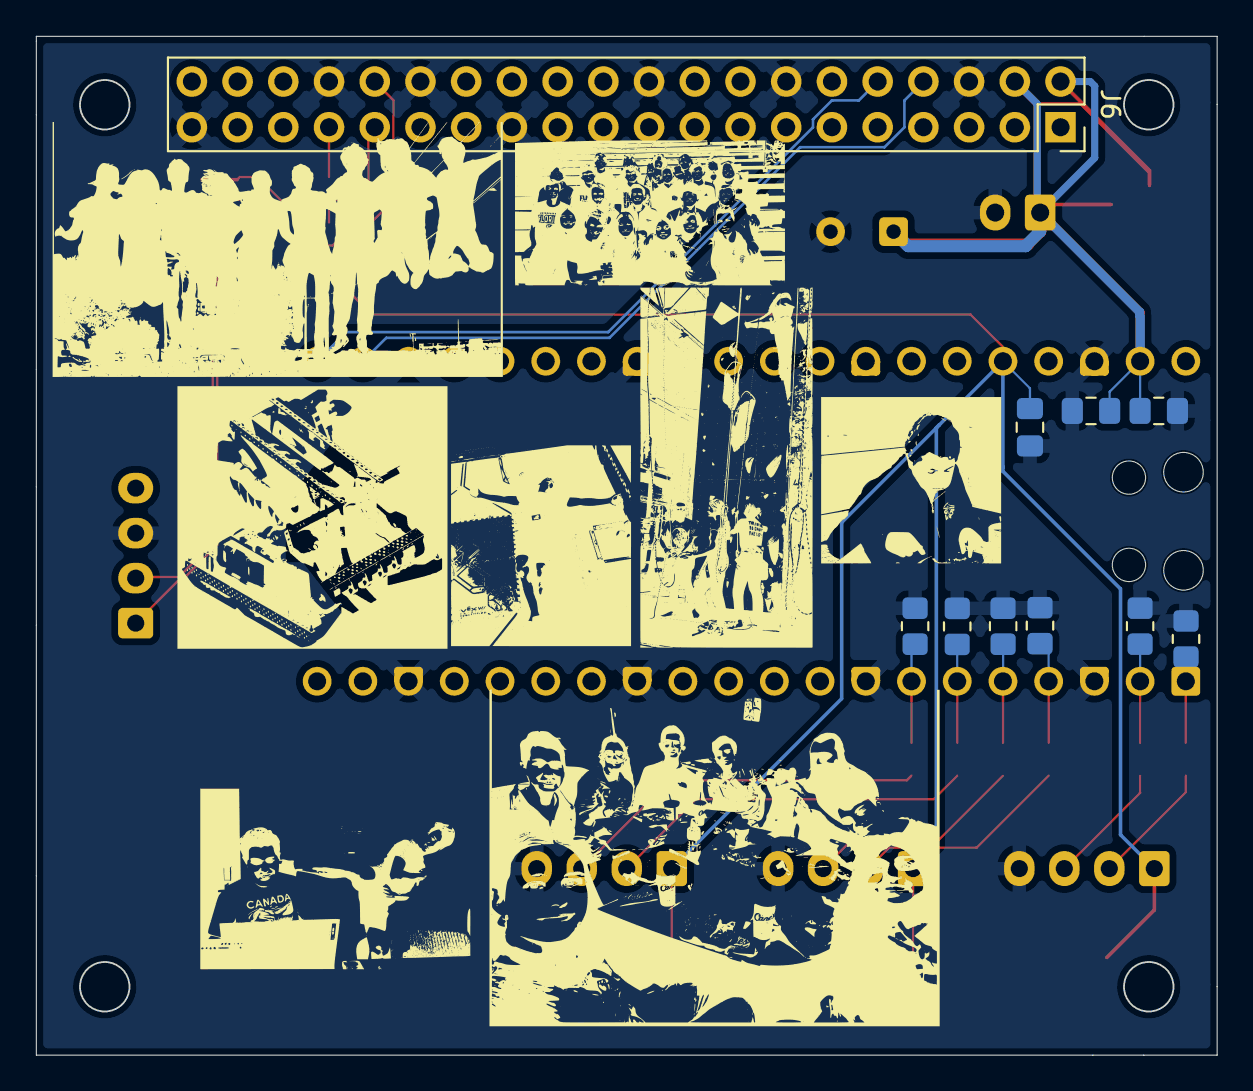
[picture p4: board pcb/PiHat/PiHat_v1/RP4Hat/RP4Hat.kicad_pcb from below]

Board: 2 copper layers, 65.6 x 56.6 mm, 31 parts (10 on the bottom side), 22 nets.

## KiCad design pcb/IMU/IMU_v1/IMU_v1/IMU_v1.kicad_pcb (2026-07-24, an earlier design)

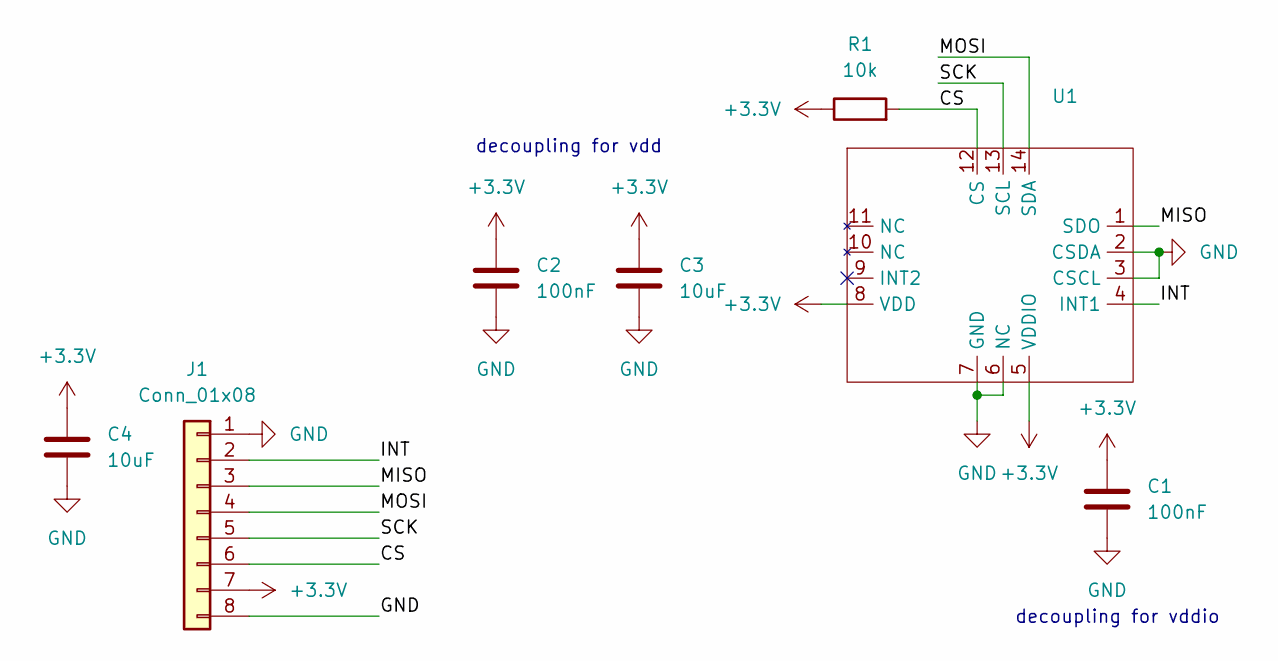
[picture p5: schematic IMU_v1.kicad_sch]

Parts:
C1, C2: 100nF; C_0805_2012Metric_Pad1.18x1.45mm_HandSolder
C3, C4: 10uF; C_0805_2012Metric_Pad1.18x1.45mm_HandSolder
J1: Conn_01x08; JST_PH_S8B-PH-K_1x08_P2.00mm_Horizontal
R1: 10k; R_0805_2012Metric_Pad1.20x1.40mm_HandSolder
U1: IMU

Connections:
+3.3V: C1.1, C2.1, C3.1, C4.1, J1.7, R1.1, U1.5 (VDDIO), U1.8 (VDD)
/CS: J1.6, R1.2, U1.12 (CS)
/INT: J1.2, U1.4 (INT1)
/MISO: J1.3, U1.1 (SDO)
/MOSI: J1.4, U1.14 (SDA)
/SCK: J1.5, U1.13 (SCL)
GND: C1.2, C2.2, C3.2, C4.2, J1.1, J1.8, U1.2 (CSDA), U1.3 (CSCL), U1.6 (NC), U1.7 (GND)

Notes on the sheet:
decoupling for vdd
decoupling for vddio

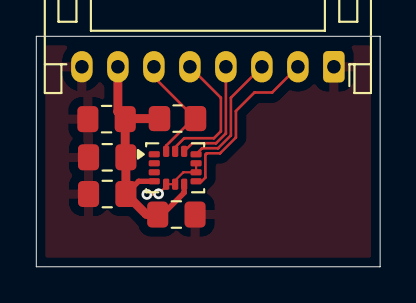
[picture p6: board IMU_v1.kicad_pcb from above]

Board: 2 copper layers, 19.1 x 12.8 mm, 7 parts (0 on the bottom side), 7 nets.

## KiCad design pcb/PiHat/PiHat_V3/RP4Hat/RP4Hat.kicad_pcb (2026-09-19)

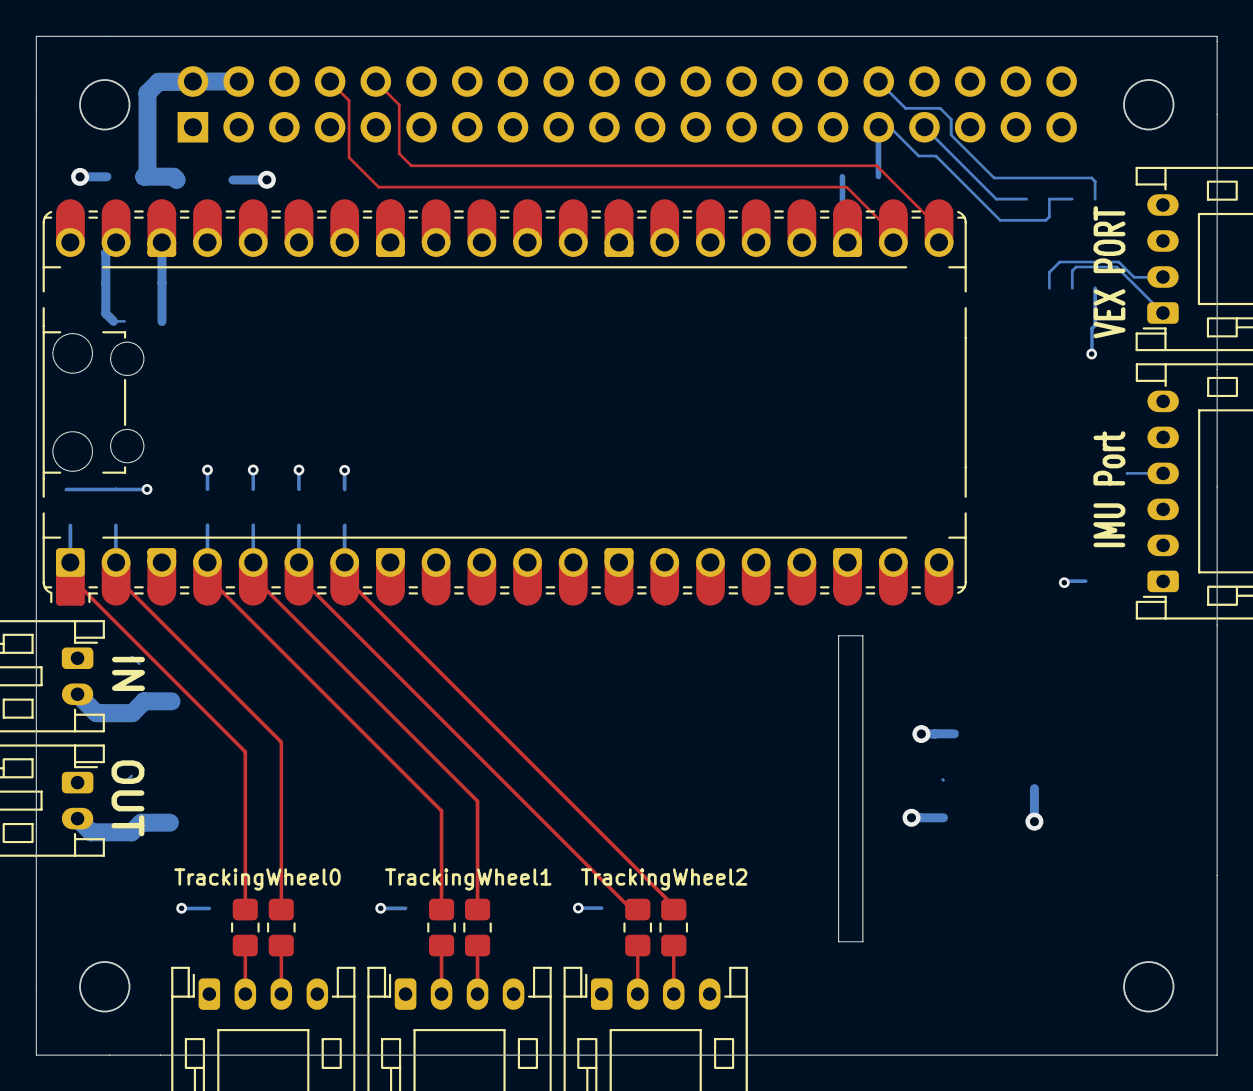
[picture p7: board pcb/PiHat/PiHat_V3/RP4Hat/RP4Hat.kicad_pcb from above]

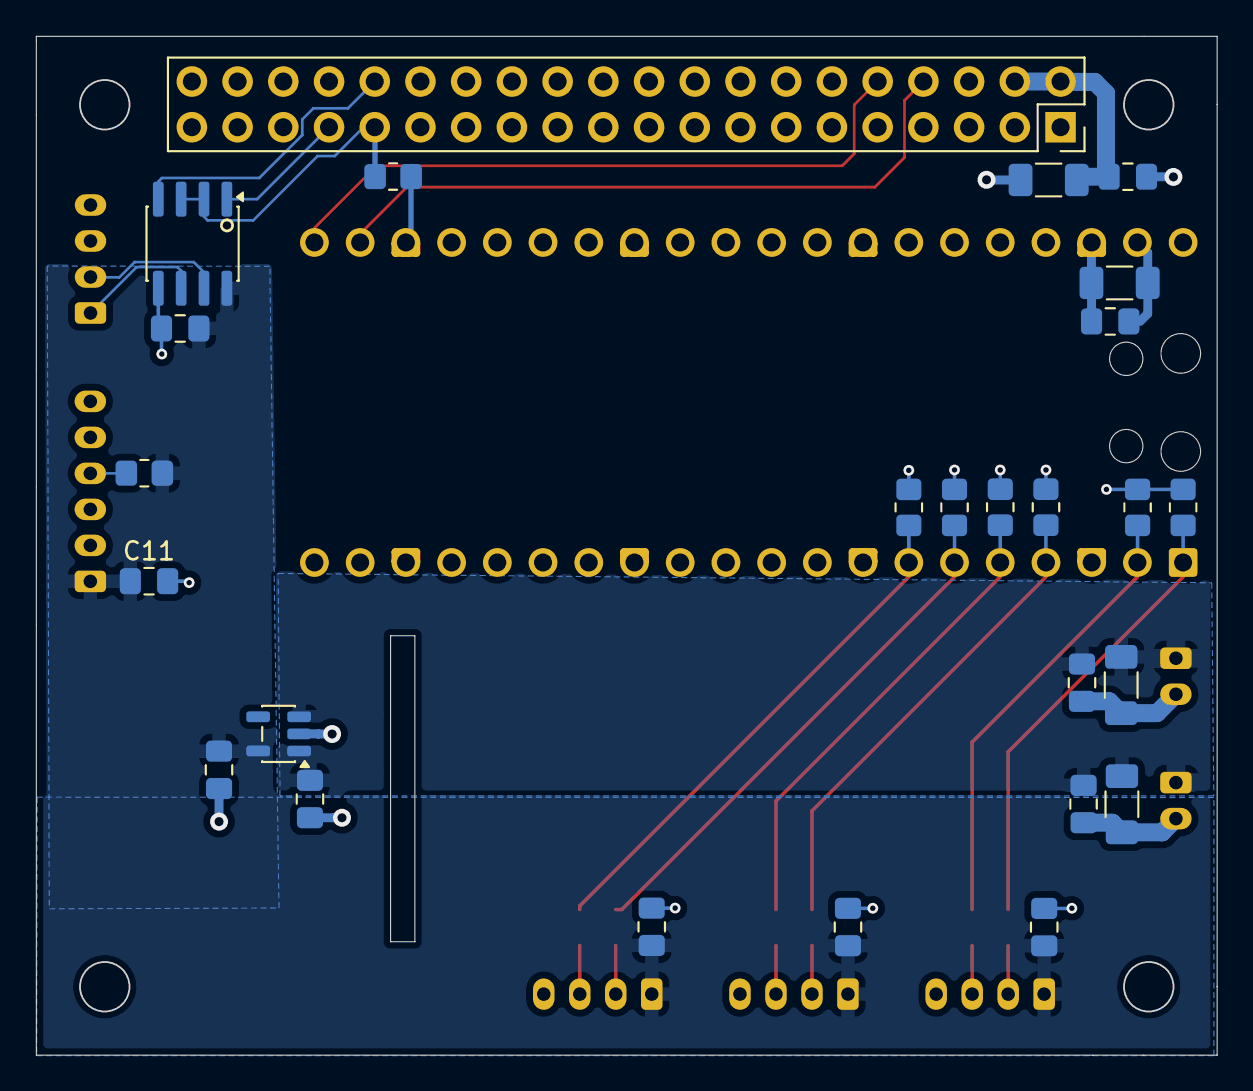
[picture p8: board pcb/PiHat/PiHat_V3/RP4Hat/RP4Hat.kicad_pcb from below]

Board: 4 copper layers, 65.6 x 56.6 mm, 40 parts (26 on the bottom side), 26 nets.

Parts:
A1: RaspberryPi_Pico; RaspberryPi_Pico_Common_Unspecified
C4, C5, C6, C8, C9, C11, C13, C14, C15, C16, C20: 1uF; C_0805_2012Metric_Pad1.18x1.45mm_HandSolder
C7, C10, C12, C17: 22uF; C_1206_3216Metric_Pad1.33x1.80mm_HandSolder
J1, J8, J9, J10: Conn_01x04; JST_PH_S4B-PH-K_1x04_P2.00mm_Horizontal
J2: Conn_01x06; JST_PH_S6B-PH-K_1x06_P2.00mm_Horizontal
J5, J11: Conn_01x02; JST_PH_S2B-PH-K_1x02_P2.00mm_Horizontal
J6: Raspberry_Pi_4; PinSocket_2x20_P2.54mm_Vertical
R1, R2, R8, R9, R10, R11, R12, R13: 10k; R_0805_2012Metric_Pad1.20x1.40mm_HandSolder
R15, R16, R17, R18, R19, R20: 100; R_0805_2012Metric_Pad1.20x1.40mm_HandSolder
U1: ST3485ECDR; SOIC-8_3.9x4.9mm_P1.27mm
U2: AP2112K-3.3; SOT-23-5

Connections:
+3.3V: C4.1, C6.1, C9.1, C11.1, C14.1, C15.1, J2.1, J8.1, J9.1, J10.1, R2.1, U1.8 (VCC), U2.5 (VOUT)
+5V: A1.39 (VSYS), C5.1, C7.1, C8.1, C10.1, C12.1, C13.1, C16.1, C17.1, C20.1, J5.1, J6.2 (5V), J6.4 (5V), J11.1, U2.1 (VIN), U2.3 (EN)
/A: J1.1, U1.6 (A)
/B: J1.2, U1.7 (B)
/EN: J6.31 (GPCLK2/GPIO06), R1.1, U1.2 (~RE), U1.3 (DE)
/IMU0_CS: A1.12 (GPIO9), J2.4, R2.2
/IMU0_MISO: A1.11 (GPIO8), J2.5
/IMU0_MOSI: A1.15 (GPIO11), J2.2
/IMU0_SCK: A1.14 (GPIO10), J2.3
/PICORX: A1.22 (GPIO17), J6.8 (GPIO14/UART_TXD)
/PICOTX: A1.21 (GPIO16), J6.10 (GPIO15/UART_RXD)
/RSRX: J6.33 (GPIO13/PWM1), U1.1 (R)
/RSTX: J6.32 (GPIO12/PWM0), U1.4 (D)
/TW0_A: A1.1 (GPIO0), R8.1, R15.2
/TW0_B: A1.2 (GPIO1), R9.1, R16.2
/TW1_A: A1.4 (GPIO2), R10.1, R17.2
/TW1_B: A1.5 (GPIO3), R11.1, R18.2
/TW2_A: A1.6 (GPIO4), R12.1, R19.2
/TW2_B: A1.7 (GPIO5), R13.1, R20.2
GND: A1.3 (GND), A1.8 (GND), A1.13 (GND), A1.18 (GND), A1.23 (GND), A1.28 (GND), A1.38 (GND), C4.2, C5.2, C6.2, C7.2, C8.2, C9.2, C10.2, C11.2, C12.2, C13.2, C14.2, C15.2, C16.2, C17.2, C20.2, J1.3, J2.6, J5.2, J6.6 (GND), J6.9 (GND), J6.14 (GND), J6.20 (GND), J6.25 (GND), J6.30 (GND), J6.34 (GND), J6.39 (GND), J8.4, J9.4, J10.4, J11.2, R1.2, R8.2, R9.2, R10.2, R11.2, R12.2, R13.2, U1.5 (GND), U2.2 (GND)
unnamed: J8.2, R15.1
unnamed: J8.3, R16.1
unnamed: J9.2, R17.1
unnamed: J9.3, R18.1
unnamed: J10.2, R19.1
unnamed: J10.3, R20.1

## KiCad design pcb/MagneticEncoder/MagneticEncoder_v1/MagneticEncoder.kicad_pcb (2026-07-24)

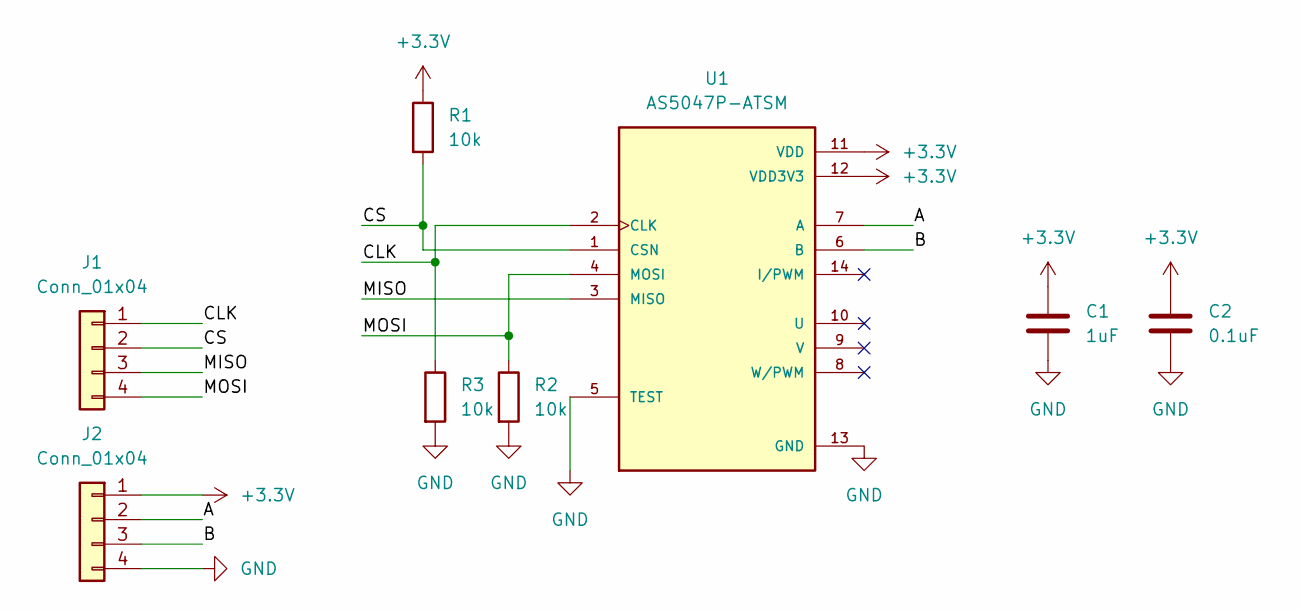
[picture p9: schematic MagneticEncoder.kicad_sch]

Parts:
C1: 1uF; C_0805_2012Metric_Pad1.18x1.45mm_HandSolder
C2: 0.1uF; C_0805_2012Metric_Pad1.18x1.45mm_HandSolder
J1: Conn_01x04; SolderWire-0.5sqmm_1x04_P4.6mm_D0.9mm_OD2.1mm
J2: Conn_01x04; JST_PH_S4B-PH-K_1x04_P2.00mm_Horizontal
R1, R2, R3: 10k; R_0805_2012Metric_Pad1.20x1.40mm_HandSolder
U1: AS5047P-ATSM; MagneticEncoder; PARTREV 1-01

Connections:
+3.3V: C1.1, C2.1, J2.1, R1.1, U1.11 (VDD), U1.12 (VDD3V3)
/A: J2.2, U1.7 (A)
/B: J2.3, U1.6 (B)
/CLK: J1.1, R3.1, U1.2 (CLK)
/CS: J1.2, R1.2, U1.1 (CSN)
/MISO: J1.3, U1.3 (MISO)
/MOSI: J1.4, R2.1, U1.4 (MOSI)
GND: C1.2, C2.2, J2.4, R2.2, R3.2, U1.5 (TEST), U1.13 (GND)

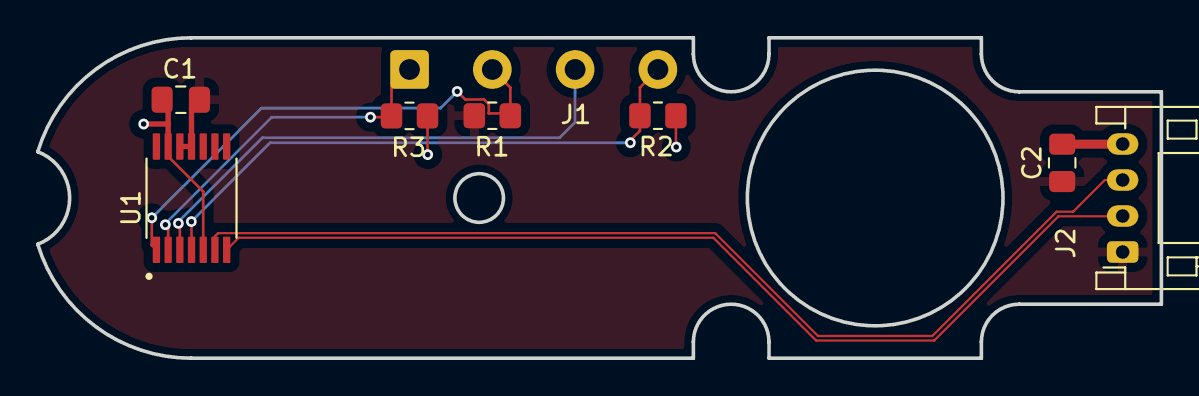
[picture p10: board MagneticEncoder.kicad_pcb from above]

Board: 2 copper layers, 62.4 x 17.8 mm, 8 parts (0 on the bottom side), 8 nets.

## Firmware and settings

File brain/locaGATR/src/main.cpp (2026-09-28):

// main.cpp
// Localization test: motor-free bench program. Sends the robot profile from
// brain/robot/gatr2_robot.h, keeps the Pi link up, places the robot once at
// program start, calibrates wheels and the IMU, and shows pose, readiness and
// recovery on the Brain screen. Move the robot by hand. With the VEX IMU it
// sends the robot tilt as TELEMETRY every 100 ms for the Pi viewer.
//
// Pages (B or the right screen button cycles):
//   Status       A place at the start pose, X recalibrate the IMU,
//                Y reinitialize the Pico IMU, hold L1+R1 and press A to
//                reinitialize localization (placement needed after)
//   Wheels       LEFT/RIGHT wheel, UP start a push, DOWN end it,
//                L1/R1 -/+1 cm, L2/R2 -/+10 cm reference, X clear trials,
//                A apply the proposed travel scale, then A again to place
//                at the last pose
//   Recovery     link, session, Pi, Pico and calibration history

#include "main.h"
#include "robot_config.h"

#include <cmath>
#include <cstdio>
#include <memory>
#include <vector>

#include "communigatr/attitude.h"
#include "communigatr/link_events.h"
#include "communigatr/pros_link.h"
#include "communigatr/pros_vex_imu.h"
#include "communigatr/startup_placement.h"
#include "communigatr/vex_imu_recalibration.h"
#include "communigatr/wheel_calibration.h"

namespace
{

using communigatr::Seconds;
using investigatr::Pose;

// ---------------------------------------------------------------------------
// Link access. Every communiGATR call of this program is in this section.
// ---------------------------------------------------------------------------

using Link = communigatr::ProsLink;

std::unique_ptr<communigatr::ProsVexImu> g_vex;
std::unique_ptr<Link>                    g_link;

Seconds now() {
    return Link::now();
}

void createLink() {
    communigatr::LinkConfig config;
    if (gatr2_robot::kUseUsb) {
        config.transport = communigatr::Transport::kUsb;
    } else {
        config.transport  = communigatr::Transport::kSmartPort;
        config.smart_port = gatr2_robot::kLinkPort;
        config.baud       = gatr2_robot::kLinkBaud;
    }
    if (gatr2_robot::kSendProfile) {
        config.profile = gatr2_robot::profile();
    }
    if (gatr2_robot::usesVexImu()) {
        g_vex.reset(new communigatr::ProsVexImu(gatr2_robot::kVexImuPort));
        communigatr::ProsVexImu* vex = g_vex.get();
        config.client.bench_imu      = [vex] { return vex->sample(); };
    }
    config.client.telemetry_period = gatr2_robot::kTelemetryPeriodMs / 1000.0;
    g_link.reset(new Link(config));
}

// Robot roll and pitch from the VEX IMU; invalid without one.
communigatr::RobotAttitude attitude() {
    if (!g_vex) {
        return communigatr::RobotAttitude{};
    }
    return communigatr::robotAttitudeFromVex(g_vex->attitude(), gatr2_robot::kVexImuMountYawDeg);
}

// TELEMETRY with the attitude group only; nothing without a valid attitude.
void sendTelemetry() {
    translagatr::BrainTelemetry t;
    communigatr::setAttitude(t, attitude());
    if (t.flags == 0) {
        return;
    }
    t.stamp_ms = pros::millis();
    g_link->reportTelemetry(t);
}

// What the screens and decisions need from the link, read once per loop.
struct View {
    bool                       started   = false;
    bool                       connected = false;
    communigatr::Readiness     readiness = communigatr::Readiness::kConnecting;
    uint32_t                   session     = 0;
    uint32_t                   pi_instance = 0;
    communigatr::ProfileStatus profile;
    bool                       state_valid = false;
    bool                       localized   = false;
    communigatr::HealthBits    health;
    uint8_t                    calibration = translagatr::kCalibrationNone;
    bool                       heading_valid = false;
    investigatr::Radians       heading       = 0; // raw Pi heading, placed or not
    investigatr::RobotState    robot;
    communigatr::LinkSnapshot  snapshot;
    bool                       telemetry_unsupported = false; // refused by the Pi this session
};

// False when the link was busy; v is then left as it was.
bool readView(Seconds t, View& v) {
    const communigatr::ProsLinkStatus s = g_link->status();
    if (s.busy) {
        return false;
    }
    v.started       = s.started;
    v.connected     = s.connected;
    v.readiness     = s.readiness;
    v.session       = s.session;
    v.pi_instance   = s.pi_instance;
    v.profile       = s.profile;
    v.state_valid   = s.state.valid;
    v.localized     = s.summary.localized;
    v.health        = s.summary.health;
    v.calibration   = s.summary.calibration;
    v.heading_valid = s.heading_valid;
    v.heading       = s.heading;
    v.telemetry_unsupported    = s.telemetry_unsupported;
    v.robot                    = g_link->robot(t);
    v.snapshot.connected       = s.connected;
    v.snapshot.session         = s.session;
    v.snapshot.pi_instance     = s.pi_instance;
    v.snapshot.profile         = s.profile.state;
    v.snapshot.state_valid     = s.state.valid;
    v.snapshot.localized       = v.localized;
    v.snapshot.health          = s.state.valid ? s.state.state.health : 0;
    v.snapshot.calibration     = v.calibration;
    v.snapshot.odometry_epoch  = s.state.state.odometry_epoch;
    v.snapshot.anchor_revision = s.state.state.anchor_revision;
    return true;
}

// Link, profile and sensors are up: the readiness got past them.
bool sensorsReady(communigatr::Readiness r) {
    using communigatr::Readiness;
    return r != Readiness::kConnecting && r != Readiness::kReconnecting &&
           r != Readiness::kProfilePending && r != Readiness::kProfileRejected &&
           r != Readiness::kSensorsUnavailable && r != Readiness::kSensorsInitializing;
}

// Pi IMU calibration not settled; a failed one waits for a recalibration.
bool calibrating(communigatr::Readiness r) {
    using communigatr::Readiness;
    return r == Readiness::kWaitingStill || r == Readiness::kCalibrating ||
           r == Readiness::kCalibrationFailed;
}

// ---------------------------------------------------------------------------
// Program state.
// ---------------------------------------------------------------------------

enum class Page : uint8_t { kStatus, kWheels, kRecovery };

enum class Capture : uint8_t { kIdle, kStart, kEnd };

struct WheelTool {
    communigatr::WheelCalibration calibration;
    const char*                   name;
};

Page                                      g_page = Page::kStatus;
communigatr::LinkEvents                   g_events;
std::unique_ptr<communigatr::StartupPlacement> g_startup;
std::vector<WheelTool>                    g_wheels;
std::size_t                               g_wheel      = 0;
double                                    g_reference  = robot_config::kCalibrationDistance;
Capture                                   g_capture    = Capture::kIdle;
communigatr::WheelTicket                  g_capture_ticket = 0;
const char*                               g_message    = "Hold still while sensors start";
char                                      g_note[64]   = {};
communigatr::PlacementTicket              g_placement  = 0;
communigatr::ControlTicket                g_control    = 0;
bool                                      g_have_last_pose = false;
Pose                                      g_last_pose;
bool                                      g_offer_place = false; // after applying a calibration
communigatr::VexImuRecalibration          g_recal; // VEX IMU, after the Pi's stillness check
uint32_t                                  g_events_seen = 0;

// True when a placement loss is among the events since the last call.
bool placementLostSinceLastCheck() {
    bool lost = false;
    for (uint32_t i = g_events_seen; i < g_events.total(); ++i) {
        const std::size_t newest = g_events.total() - 1 - i;
        lost = lost || (newest < g_events.size() &&
                        g_events.at(newest).event == communigatr::LinkEvent::kPlacementLost);
    }
    g_events_seen = g_events.total();
    return lost;
}

void buildWheelTools() {
    const communigatr::RobotProfile p      = gatr2_robot::profile();
    const auto                      config = robot_config::wheelCalibration();
    for (std::size_t i = 0; i < p.wheels.size(); ++i) {
        // Cross wheels: those measuring roughly perpendicular to this one.
        std::vector<uint8_t> cross;
        for (std::size_t j = 0; j < p.wheels.size(); ++j) {
            const double between = std::fabs(investigatr::wrapAngle(p.wheels[j].angle - p.wheels[i].angle));
            if (j != i && std::fabs(between - investigatr::kPi / 2) < investigatr::kPi / 8) {
                cross.push_back(p.wheels[j].encoder_port);
            }
        }
        const bool forward = std::fabs(std::sin(p.wheels[i].angle)) < 0.5;
        g_wheels.push_back(WheelTool{
            communigatr::WheelCalibration(p.wheels[i], cross, config),
            forward ? "forward" : "sideways"});
    }
}

communigatr::CalibrationSnapshot snapshotFrom(const communigatr::WheelReadings& r, const View& v) {
    communigatr::CalibrationSnapshot s;
    s.profile_id    = v.profile.id;
    s.heading_valid = v.heading_valid;
    s.heading       = v.heading;
    for (uint8_t i = 0; i < r.count && i < translagatr::kWheelReadingsMax; ++i) {
        communigatr::WheelSample w = communigatr::fromReading(r.wheels[i]);
        // Age at the time of use: the Pi's age plus the time since the reply.
        w.age += now() - r.received_at + r.round_trip;
        s.wheels.push_back(w);
    }
    return s;
}

bool pressed(pros::Controller& c, pros::controller_digital_e_t button) {
    return c.is_connected() == 1 && c.get_digital_new_press(button) == 1;
}

bool held(pros::Controller& c, pros::controller_digital_e_t button) {
    return c.is_connected() == 1 && c.get_digital(button) == 1;
}

bool poseLive(const View& v) {
    return v.robot.valid() && v.robot.age <= robot_config::kMaxPoseAgeSeconds;
}

void placeAt(const Pose& pose, const char* done) {
    const communigatr::PlacementTicket t = g_link->place(pose);
    if (t == 0) {
        g_message = "Place refused: link, profile or a pending placement";
        return;
    }
    g_placement = t;
    g_message   = done;
}

void startControl(communigatr::ControlTicket t, const char* done) {
    if (t == 0) {
        g_message = "Refused: no link, or another request pending";
        return;
    }
    g_control = t;
    g_message = done;
}

// ---------------------------------------------------------------------------
// Pages.
// ---------------------------------------------------------------------------

void statusInput(pros::Controller& c, const View& v) {
    if (pressed(c, pros::E_CONTROLLER_DIGITAL_A)) {
        if (held(c, pros::E_CONTROLLER_DIGITAL_L1) && held(c, pros::E_CONTROLLER_DIGITAL_R1)) {
            startControl(g_link->reinitialize(), "Reinitializing: place the robot after");
        } else if (!v.connected) {
            g_message = "No link; connect, then A again";
        } else {
            placeAt(gatr2_robot::kStartPose, "Placing at the start pose");
        }
    }
    if (pressed(c, pros::E_CONTROLLER_DIGITAL_X)) {
        if (g_vex) {
            // The Pi checks the robot is still, then the VEX firmware
            // calibrates; the Pi holds the pose meanwhile.
            g_message = g_recal.begin(g_link->recalibrate())
                            ? "Checking the robot is still..."
                            : "Refused: no link, or another request pending";
        } else {
            startControl(g_link->recalibrate(), "IMU recalibration requested: hold still");
        }
    }
    if (pressed(c, pros::E_CONTROLLER_DIGITAL_Y)) {
        if (g_vex) {
            g_message = "Y reinitializes the Pico IMU; this profile uses the VEX IMU";
        } else {
            startControl(g_link->reinitImu(), "Pico IMU reinitializing: hold still");
        }
    }
}

void wheelsInput(pros::Controller& c, const View& v) {
    if (g_wheels.empty()) {
        return;
    }
    if (pressed(c, pros::E_CONTROLLER_DIGITAL_LEFT)) {
        g_wheel   = (g_wheel + g_wheels.size() - 1) % g_wheels.size();
        g_capture = Capture::kIdle;
    }
    if (pressed(c, pros::E_CONTROLLER_DIGITAL_RIGHT)) {
        g_wheel   = (g_wheel + 1) % g_wheels.size();
        g_capture = Capture::kIdle;
    }
    const double steps[4] = {-0.01, 0.01, -0.1, 0.1};
    const pros::controller_digital_e_t keys[4] = {
        pros::E_CONTROLLER_DIGITAL_L1, pros::E_CONTROLLER_DIGITAL_R1,
        pros::E_CONTROLLER_DIGITAL_L2, pros::E_CONTROLLER_DIGITAL_R2};
    for (int i = 0; i < 4; ++i) {
        if (pressed(c, keys[i])) {
            g_reference = std::round((g_reference + steps[i]) * 100.0) / 100.0;
        }
    }
    if (pressed(c, pros::E_CONTROLLER_DIGITAL_UP) || pressed(c, pros::E_CONTROLLER_DIGITAL_DOWN)) {
        const bool                     start  = c.get_digital(pros::E_CONTROLLER_DIGITAL_UP) == 1;
        const communigatr::WheelTicket ticket = g_link->requestWheels();
        if (ticket == 0) {
            g_message = "Cannot read the wheels: no link, or a read pending";
        } else {
            g_capture        = start ? Capture::kStart : Capture::kEnd;
            g_capture_ticket = ticket;
            g_message        = start ? "Reading start..." : "Reading end...";
        }
    }
    if (pressed(c, pros::E_CONTROLLER_DIGITAL_X)) {
        g_wheels[g_wheel].calibration.clear();
        g_message = "Trials cleared";
    }
    if (pressed(c, pros::E_CONTROLLER_DIGITAL_A)) {
        if (g_offer_place) {
            g_offer_place = false;
            placeAt(g_last_pose, "Placing at the pose before the change");
            return;
        }
        if (!gatr2_robot::kSendProfile) {
            g_message = "Apply needs a Brain profile config (kSendProfile); copy the scale by hand";
            return;
        }
        const communigatr::CalibrationProposal p = g_wheels[g_wheel].calibration.proposal();
        if (!p.ready) {
            g_message = "Need 3 agreeing trials before applying";
            return;
        }
        communigatr::RobotProfile profile = g_link->profile();
        for (communigatr::TrackingWheel& w : profile.wheels) {
            if (w.encoder_port == g_wheels[g_wheel].calibration.port()) {
                w.travel_scale = p.scale;
            }
        }
        g_have_last_pose = poseLive(v);
        if (g_have_last_pose) {
            g_last_pose = v.robot.pose;
        }
        if (!g_link->setProfile(profile)) {
            g_message = "Profile refused by the Brain check";
            return;
        }
        std::snprintf(g_note, sizeof(g_note), "Port %u travel_scale = %.4f (copy to gatr2_robot.h)",
                      unsigned(g_wheels[g_wheel].calibration.port()), p.scale);
        g_offer_place = g_have_last_pose;
        g_message     = g_offer_place ? "Applied; A places at the last pose" : "Applied; place again";
    }
}

// Finishes a wheel capture once its read settles.
void serviceCapture(const View& v) {
    if (g_capture == Capture::kIdle) {
        return;
    }
    const communigatr::WheelStatus w = g_link->wheels(g_capture_ticket);
    if (w.state == communigatr::WheelResult::kPending) {
        return;
    }
    const Capture step = g_capture;
    g_capture          = Capture::kIdle;
    if (w.state == communigatr::WheelResult::kRejected) {
        std::snprintf(g_note, sizeof(g_note), "Wheel read refused (result %u): profile applied?",
                      unsigned(w.result));
        g_message = g_note;
        return;
    }
    if (w.state != communigatr::WheelResult::kOk) {
        g_message = "No answer to the wheel read: press again";
        return;
    }
    const communigatr::CalibrationSnapshot s = snapshotFrom(w.readings, v);
    communigatr::WheelCalibration&         cal = g_wheels[g_wheel].calibration;
    const communigatr::TrialStatus status =
        step == Capture::kStart ? cal.start(s) : cal.finish(s, g_reference);
    if (status == communigatr::TrialStatus::kAccepted) {
        g_message = step == Capture::kStart ? "Push along the wheel, then DOWN" : "Trial accepted";
    } else {
        std::snprintf(g_note, sizeof(g_note), "Rejected: %s", communigatr::toString(status));
        g_message = g_note;
    }
}

// ---------------------------------------------------------------------------
// Screen.
// ---------------------------------------------------------------------------

constexpr int kButtonTop = 208;

template <typename... Args> void row(int index, const char* format, Args... args) {
    const int y = 4 + index * 20;
    pros::screen::erase_rect(0, y, 479, y + 19);
    pros::screen::print(pros::E_TEXT_MEDIUM, 6, y, format, args...);
}

void showStatus(const View& v) {
    row(1, "%s | %s", gatr2_robot::kUseUsb ? "USB" : "RS-485", communigatr::toString(v.readiness));
    row(2, "Profile %08lx %s", static_cast<unsigned long>(v.profile.id),
        v.profile.state == communigatr::ProfileSync::kRejected
            ? communigatr::profileReasonName(v.profile.reason)
            : "");
    if (v.robot.valid()) {
        row(3, "x %+.3f  y %+.3f m  h %+.2f deg", v.robot.pose.x, v.robot.pose.y,
            v.robot.pose.heading * 180.0 / investigatr::kPi);
        row(4, "Pose %s, age %.0f ms", poseLive(v) ? "LIVE" : "STALE", v.robot.age * 1000.0);
    } else {
        row(3, "x --  y --  h --");
        row(4, "Pose: %s", investigatr::toString(v.robot.status));
    }
    row(5, "Enc %s  IMU %s  Pico %s  Still %s", v.health.encoders_fresh ? "ok" : "--",
        v.health.imu_fresh ? "ok" : "--", v.health.pico_link ? "ok" : "--",
        v.health.stationary ? "yes" : "no");
    if (g_vex) {
        const communigatr::BenchImuSample imu = g_vex->sample();
        const communigatr::RobotAttitude  a   = attitude();
        if (g_recal.active() || !a.valid) {
            row(6, "VEX IMU P%u: %s %+.2f deg  recal %s", unsigned(gatr2_robot::kVexImuPort),
                g_vex->calibrating() ? "calibrating" : imu.valid ? "ok" : "unavailable",
                imu.rotation_mdeg / 1000.0, communigatr::toString(g_recal.state()));
        } else {
            // Robot frame tilt, for the mount check in docs/brain_setup.md.
            // "no TM": the Pi refused TELEMETRY (older Pi).
            row(6, "VEX P%u ok %+.1f deg  r %+.1f p %+.1f%s", unsigned(gatr2_robot::kVexImuPort),
                imu.rotation_mdeg / 1000.0, a.roll_rad * 180.0 / investigatr::kPi,
                a.pitch_rad * 180.0 / investigatr::kPi, v.telemetry_unsupported ? " (no TM)" : "");
        }
    } else {
        row(6, "Pi IMU calibration: %s%s", communigatr::calibrationName(v.calibration),
            v.calibration == translagatr::kCalibrationFailed ? " (X retries)" : "");
    }
    row(7, "Start placement: %s", communigatr::toString(g_startup->state()));
    row(8, "A place  X recal IMU  Y Pico IMU  L1+R1+A reinit");
}

void showWheels() {
    if (g_wheels.empty()) {
        row(1, "No tracking wheels in the profile");
        return;
    }
    const WheelTool&                         tool = g_wheels[g_wheel];
    const communigatr::CalibrationProposal   p    = tool.calibration.proposal();
    const communigatr::WheelReadings&        r    = g_link->wheelReadings();
    double                                   travel = 0;
    for (uint8_t i = 0; i < r.count; ++i) {
        if (r.wheels[i].port == tool.calibration.port()) {
            travel = r.wheels[i].travel_um * 1e-6;
        }
    }
    row(1, "Wheel port %u (%s)  %s", unsigned(tool.calibration.port()), tool.name,
        tool.calibration.started() ? "PUSHING" : "");
    row(2, "Reference %.2f m (L1/R1 1 cm, L2/R2 10 cm)", g_reference);
    row(3, "Raw travel %.4f m (last read)", travel);
    row(4, "Trials %u  scale %.4f  spread %.2f%%", unsigned(p.trials), p.scale, p.spread * 100.0);
    const auto& trials = tool.calibration.trials();
    for (std::size_t i = 0; i < 3; ++i) {
        if (i < trials.size()) {
            const auto& t = trials[trials.size() - 1 - i];
            row(5 + static_cast<int>(i), "  ref %.3f  wheel %.4f  scale %.4f", t.reference,
                t.measured, t.scale);
        } else {
            row(5 + static_cast<int>(i), "");
        }
    }
    row(8, p.ready ? "READY: A applies  UP start  DOWN end  X clear" : "UP start  DOWN end  X clear");
}

void showRecovery() {
    for (int i = 0; i < 8; ++i) {
        if (static_cast<std::size_t>(i) < g_events.size()) {
            const communigatr::LinkEventRecord& e = g_events.at(static_cast<std::size_t>(i));
            if (e.event == communigatr::LinkEvent::kLinkRestored) {
                row(1 + i, "%7.1f s  %s after %.1f s", e.at, communigatr::toString(e.event),
                    e.duration);
            } else {
                row(1 + i, "%7.1f s  %s", e.at, communigatr::toString(e.event));
            }
        } else {
            row(1 + i, "");
        }
    }
}

void display(const View& v) {
    const char* titles[] = {"Status", "Wheel calibration", "Recovery"};
    row(0, "Localization test | %s", titles[static_cast<int>(g_page)]);
    switch (g_page) {
    case Page::kStatus: showStatus(v); break;
    case Page::kWheels: showWheels(); break;
    case Page::kRecovery: showRecovery(); break;
    }
    row(9, "%s", g_message);
    pros::screen::set_pen(0x00304B60);
    pros::screen::fill_rect(0, kButtonTop, 479, 239);
    pros::screen::set_pen(0x00FFFFFF);
    pros::screen::print(pros::E_TEXT_MEDIUM, 12, kButtonTop + 6, "PLACE AT START");
    pros::screen::print(pros::E_TEXT_MEDIUM, 330, kButtonTop + 6, "NEXT PAGE");
    pros::screen::set_pen(0x00FFFFFF);
}
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
void opcontrol() {
    while (true) {
        pros::delay(20);
    }
}

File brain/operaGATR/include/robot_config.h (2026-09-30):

// robot_config.h
// Testing program settings: drivetrain, movement limits and gains, test
// destinations and controls. The robot's localization description (tracking
// wheels, IMU, footprint, Pi link, start pose) is shared by every program:
// brain/robot/gatr2_robot.h.
//
// PLACEHOLDER: depends on how the robot is built; set before driving.
// Units: meters, radians, seconds. Field frame +x right, +y up on the field
// diagram, heading CCW from +x. Robot frame +x forward, +y left.

#pragma once
#include <cstdint>

#include "actugatr/drive.h"
#include "actugatr/drive_owner.h"
#include "actugatr/drivetrain.h"
#include "actugatr/follower.h"
#include "actugatr/motion.h"
#include "api.h"
#include "communigatr/startup_placement.h"
#include "field_references.h"
#include "gatr2_robot.h"

namespace robot_config
{

constexpr double kDeg = investigatr::kPi / 180.0;
constexpr double kInch = 0.0254;

// ---------------------------------------------------------------------------
// Drivetrain. Pick one, then fill in its block below.
//   kTank     left and right sides, 1 to 4 motors per side
//   kMecanum  four wheels, each driven on its own, 1 to 4 motors per wheel
//             (usually one)
//
// Motors are {Smart Port, reversed}. reversed = true for a motor that spins
// backward when told to drive forward (usually every motor on one side).
// Check with the wheels off the ground: sticks forward slowly, every driven
// wheel must roll forward. A port
// may not repeat or be the VEX IMU port; the program refuses to drive if one
// does.
//
// Every value marked PLACEHOLDER below is a guess. Replace it with your
// robot's value before driving.
// ---------------------------------------------------------------------------
enum class Drivetrain : uint8_t { kTank, kMecanum };
constexpr Drivetrain kDrivetrain = Drivetrain::kMecanum;

// Shared wheel settings, the same for tank and mecanum.
inline actugatr::WheelDrive drivenWheels(double diameter, double gear_ratio) {
    actugatr::WheelDrive w;
    // Confirmed blue 600 RPM cartridges for the tank and mecanum builds.
    w.cartridge = actugatr::Cartridge::kBlue;
    // Share of top speed used, headroom for the motor's speed loop.
    w.usable_fraction = 0.9;
    w.wheel_diameter  = diameter;
    w.gear_ratio      = gear_ratio;
    return w;
}

inline actugatr::TankConfig tank() {
    actugatr::TankConfig c;
    // Every motor on the left side, then every motor on the right. reversed
    // true is a negative port in PROS terms.
    c.left  = actugatr::motorGroup({
        {18, true},  // front
        {15, false}, // middle
        {11, true},  // rear
        {13, true},  // aux
    });

    c.right = actugatr::motorGroup({
        {19, false}, // front
        {16, true},  // middle
        {12, false}, // rear
        {14, false}, // aux
    });
    // Full left-to-right driven-wheel center spacing, 10.65 inches.
    c.track_width = 10.65 * kInch;
    // 2.75-inch driven wheels, 1:1 external gearing (wheel turns/motor turn).
    c.wheels    = drivenWheels(2.75 * kInch, 1.0);
    c.stop_mode = actugatr::StopMode::kBrake;
    return c;
}

inline actugatr::MecanumConfig mecanum() {
    actugatr::MecanumConfig c;
    // Four motors: corners named facing forward from behind the robot.
    // Positive wheel commands should roll forward: 2/12 normal, 1/11 reversed.
    // Verify all directions with the wheels lifted.
    // Standard X roller layout only: matching wheel handedness on opposite
    // diagonals. A/B wheel labels are mechanical, not motor reversal flags.
    c.front_left  = actugatr::motorGroup({{12, false}});
    c.front_right = actugatr::motorGroup({{11, true}});
    c.rear_left   = actugatr::motorGroup({{2, false}});
    c.rear_right  = actugatr::motorGroup({{1, true}});
    // Measured full spans: 22.3 cm between left/right tread centerlines,
    // 24.2 cm between front/rear shafts. Origin is this rectangle's center.
    c.track_width = 0.223;
    c.wheelbase   = 0.242;
    // Approximately 70 mm mecanum wheel diameter.
    // Confirmed 1:1 direct drive: motor -> shaft -> wheel.
    c.wheels    = drivenWheels(0.070, 1.0);
    c.stop_mode = actugatr::StopMode::kBrake;
    return c;
}

// ---------------------------------------------------------------------------
// Movement. Clearance is added around the footprint for obstacle avoidance;
// keep the follower tracking_tolerance below it.
// ---------------------------------------------------------------------------
constexpr double kClearance = 0.06;

// Safe starting limits; raise them after the first runs. Speed and turn rate
// are also capped at what the drivetrain above can reach.
inline investigatr::MotionLimits limits() {
    investigatr::MotionLimits l;
    l.max_speed = 0.8; // m/s
    l.max_accel = 1.5; // m/s^2
    l.max_omega = 3.0; // rad/s
    l.max_alpha = 6.0; // rad/s^2
    return l;
}
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

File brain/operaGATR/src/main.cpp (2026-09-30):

// main.cpp
// GATR2 testing program: localization from the Pi, planning from
// investiGATR, following and drive control from actuGATR. The robot profile
// comes from brain/robot/gatr2_robot.h, the drivetrain, gains and tests from
// include/robot_config.h.
//
// Controller: left stick Y forward, right stick X turn, left stick X strafe
// (mecanum). A direct test, X avoiding test, Y landmark test, B cancel, UP
// place at the start pose, DOWN recalibrate the IMU (drive idle, robot
// still), LEFT/RIGHT speed scale. autonomous() runs the direct then the
// avoiding test. The drive task is the only motor writer. The background
// task sends TELEMETRY (movement, wheel targets, VEX IMU tilt) every 100 ms
// for the Pi viewer and recordings.

#include "main.h"
#include "robot_config.h"

#include <cmath>
#include <cstdio>
#include <memory>

#include "actugatr/drive_owner.h"
#include "actugatr/ports.h"
#include "actugatr/pros_drive.h"
#include "actugatr/pros_motor_output.h"
#include "actugatr/telemetry.h"
#include "communigatr/attitude.h"
#include "communigatr/link_events.h"
#include "communigatr/pros_link.h"
#include "communigatr/pros_vex_imu.h"
#include "communigatr/startup_placement.h"
#include "communigatr/vex_imu_recalibration.h"
#include "investigatr/planner.h"

namespace
{

using communigatr::Seconds;
using investigatr::Pose;

std::unique_ptr<communigatr::ProsVexImu>       g_vex;
std::unique_ptr<communigatr::ProsLink>         g_link;
std::unique_ptr<investigatr::GeometricPlanner> g_planner;
std::unique_ptr<actugatr::Follower>            g_follower;
std::unique_ptr<actugatr::Motion>              g_motion;
std::unique_ptr<actugatr::Kinematics>          g_kinematics;
std::unique_ptr<actugatr::ProsMotorOutput>     g_motors;
std::unique_ptr<actugatr::Drive>               g_drive;
std::unique_ptr<actugatr::DriveOwner>          g_owner;
std::unique_ptr<actugatr::ProsDrive>           g_task;
std::unique_ptr<communigatr::StartupPlacement> g_startup;
communigatr::LinkEvents                        g_events;

char        g_config_error[80] = {};
const char* g_message        = "Starting";
double      g_speed_scale    = robot_config::kSpeedScale;

Seconds now() {
    return communigatr::ProsLink::now();
}

bool motionReady() {
    return g_task != nullptr;
}

bool tank() {
    return robot_config::kDrivetrain == robot_config::Drivetrain::kTank;
}

investigatr::MotionModel model() {
    return tank() ? actugatr::motionModel(robot_config::tank(), gatr2_robot::kFootprint,
                                          robot_config::kClearance, robot_config::limits())
                  : actugatr::motionModel(robot_config::mecanum(), gatr2_robot::kFootprint,
                                          robot_config::kClearance, robot_config::limits());
}

bool configError(const char* what, const char* why) {
    std::snprintf(g_config_error, sizeof(g_config_error), "%s: %s", what, why ? why : "invalid");
    return false;
}

// Every active Smart Port device on its own port and every drive setting
// valid, or no motors at all.
bool checkConfig() {
    actugatr::PortMap map;
    if (tank()) {
        map.add(robot_config::tank());
    } else {
        map.add(robot_config::mecanum());
    }
    if (gatr2_robot::usesVexImu()) {
        map.add(gatr2_robot::kVexImuPort, "VEX IMU");
    }
    if (!gatr2_robot::kUseUsb) {
        map.add(gatr2_robot::kLinkPort, "Pi link");
    }
    if (!map.ok()) {
        return configError("ports", map.error());
    }
    const char* why = nullptr;
    if (tank() ? !actugatr::valid(robot_config::tank(), &why)
               : !actugatr::valid(robot_config::mecanum(), &why)) {
        return configError("drivetrain", why);
    }
    const actugatr::FollowerConfig follower = robot_config::follower();
    if (!actugatr::valid(follower, &why)) {
        return configError("follower", why);
    }
    if (!actugatr::valid(robot_config::motion(model()), &why)) {
        return configError("motion", why);
    }
    // The planner's clearance must cover the most drift the follower allows.
    if (!(std::hypot(follower.position_tolerance, follower.tracking_tolerance) <
          robot_config::kClearance)) {
        return configError("follower", "tolerances not below kClearance");
    }
    return true;
}

void createLink() {
    communigatr::LinkConfig config;
    if (gatr2_robot::kUseUsb) {
        config.transport = communigatr::Transport::kUsb;
    } else {
        config.transport  = communigatr::Transport::kSmartPort;
        config.smart_port = gatr2_robot::kLinkPort;
        config.baud       = gatr2_robot::kLinkBaud;
    }
    if (gatr2_robot::kSendProfile) {
        config.profile = gatr2_robot::profile();
    }
    if (gatr2_robot::usesVexImu()) {
        g_vex.reset(new communigatr::ProsVexImu(gatr2_robot::kVexImuPort));
        communigatr::ProsVexImu* vex = g_vex.get();
        config.client.bench_imu      = [vex] { return vex->sample(); };
    }
    config.client.telemetry_period = gatr2_robot::kTelemetryPeriodMs / 1000.0;
    g_link.reset(new communigatr::ProsLink(config));
}
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

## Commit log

2026-07-19 Create README.md
    add pico folder where all pico firmware will live.
2026-07-19 Create README.md
    setupfolder for all PCB related files (schematics, layouts, docs, etc...)
2026-07-19 add preliminary frame format, simple gtest, and ci, reformat folders a tiny bit
2026-07-20 setup clang format... reformat frames.h to fit that format, add interfaces document to explain how the frames are defined
2026-07-24 add pcb designs for HAT (v0 and v1, IMU) and encoders which were previously designed already
    [IMU_v1.kicad_pcb, IMU_v1.kicad_sch, MagneticEncoder.kicad_pcb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]
2026-07-27 new stuff.....
    [LinearRegulator.kicad_sch, RP4Hat.kicad_sch, untitled.kicad_sch]
2026-07-27 made new imu project and added symbols/footprint
    [IMU_v1.kicad_sch, IMU_v2.kicad_pcb, IMU_v2.kicad_sch]
2026-09-06 moving to differeent device
    [LinearRegulator.kicad_sch, RP4Hat.kicad_pcb, RP4Hat.kicad_sch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]
2026-09-06 new stuff...
    [SPI_IMU.kicad_sch, TrackingWheel.kicad_sch]
2026-09-08 reorganize schematic into subsheets
    [RP4Hat.kicad_sch]
2026-09-08 move pulldown resistor into sheet
    [RP4Hat.kicad_sch, VexBrainPort.kicad_sch]
2026-09-08 organize schematic further, no functional changes
    [RP4Hat.kicad_sch, SPI_IMU.kicad_sch]
2026-09-15 big potato shi
    [RP4Hat.kicad_pcb, RP4Hat.kicad_sch, SPI_IMU.kicad_sch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]
2026-09-15 add supporting docs
    [RP4Hat.kicad_pcb]
2026-09-19 pcb changes
    [IMU_v1.kicad_pcb, IMU_v1.kicad_sch, IMU_v2.kicad_pcb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]
2026-09-26 new stuff
    [RP4Hat.kicad_sch]
2026-09-27 usb fix
    [RP4Hat.kicad_pcb]
2026-09-30 failed testing day 2
    [LinearRegulator.kicad_sch, RP4Hat.kicad_pcb, RP4Hat.kicad_sch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]
2026-10-09 Keep retired software local and restore PCB design history
2026-10-12 Track retired software, notes and 3D models
